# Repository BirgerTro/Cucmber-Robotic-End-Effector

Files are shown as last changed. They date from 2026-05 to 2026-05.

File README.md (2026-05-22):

# Cucmber-Robotic-End-Effector
Proof-of-concept robotic end-effector for autonomous cucumber harvesting in vertical farming. Features soft pneumatic silicone fingers, a rack-and-pinion cutting mechanism, and a rotating roll positioning system. Includes Arduino control code, Python analysis scripts and STEP-files of the relevant designsNTNU Master's thesis, 2026

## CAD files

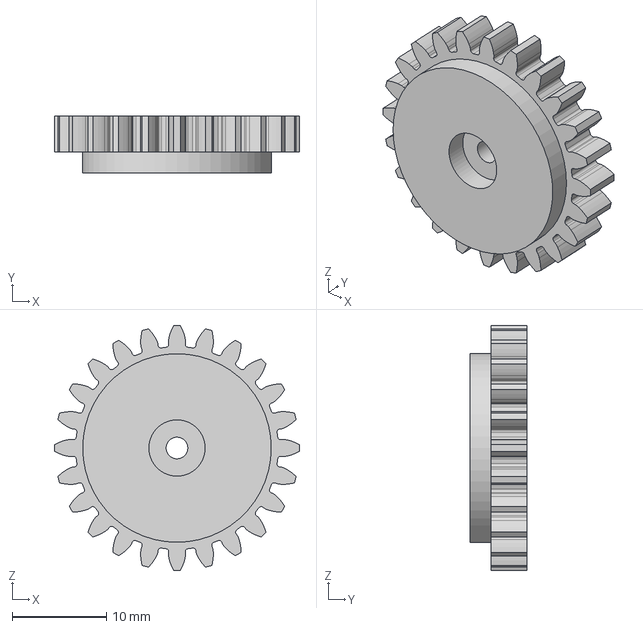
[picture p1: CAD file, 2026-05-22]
STEPfiles/Cutting_system/Knife_spurgear.step
26.0 x 6.01 x 26.0 mm

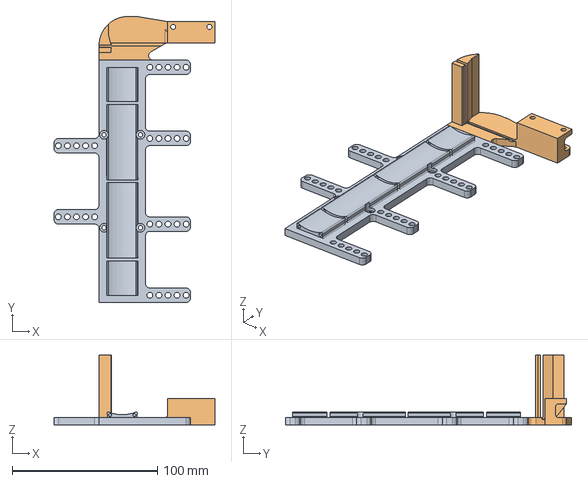
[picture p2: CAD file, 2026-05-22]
STEPfiles/Mechanical_assembly/Palm-with-knife-holder.step
110.9 x 197.0 x 48.0 mm
Mount
Knivoppsettholder

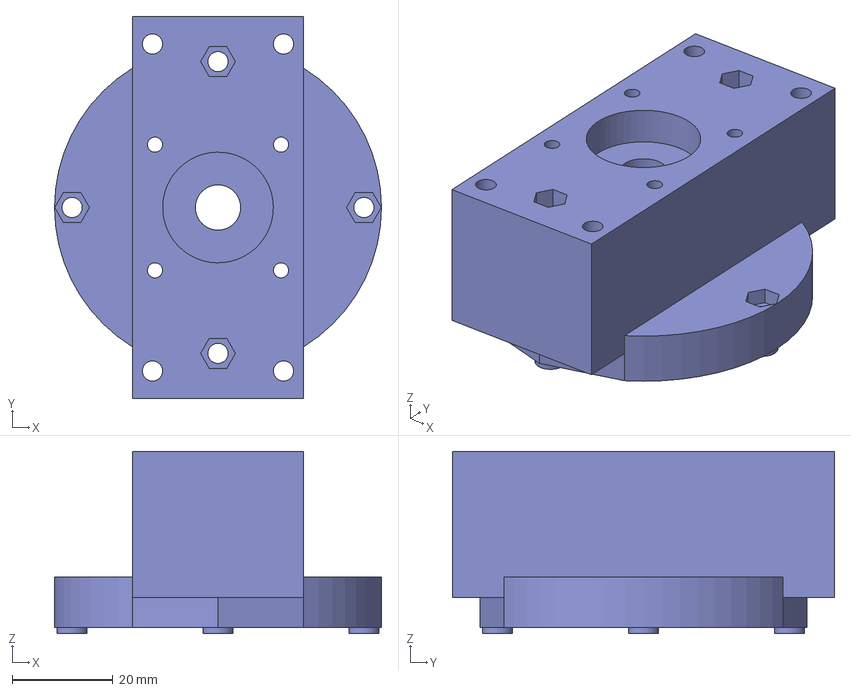
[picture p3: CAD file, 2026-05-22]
STEPfiles/Rotating_system/Wrist-mount.step
65.0 x 76.0 x 36.2 mm

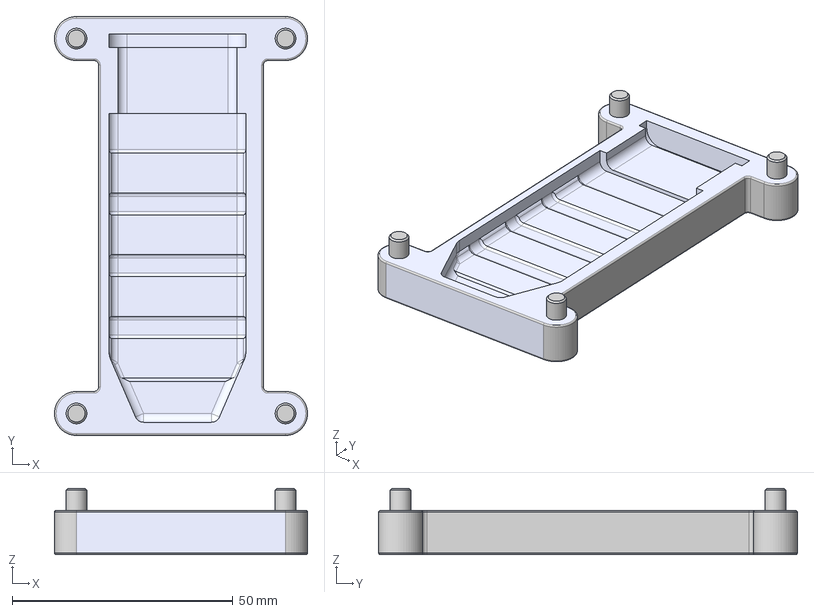
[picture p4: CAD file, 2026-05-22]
STEPfiles/Silicone_fingers/Bottom-mold.step
57.4 x 95.0 x 15.0 mm

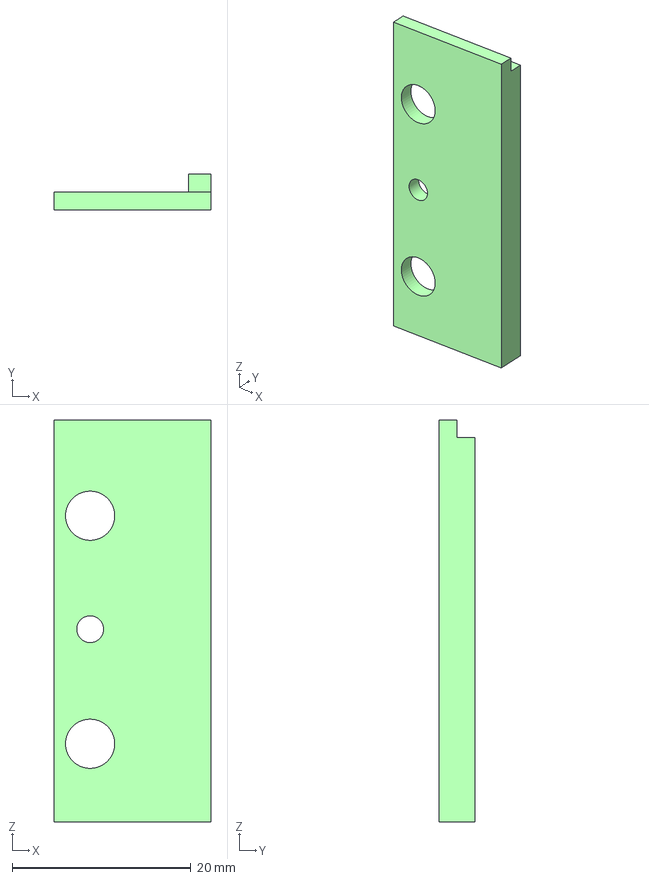
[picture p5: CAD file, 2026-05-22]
STEPfiles/Cutting_system/razorblade-holder.step
17.5 x 4.00 x 45.0 mm

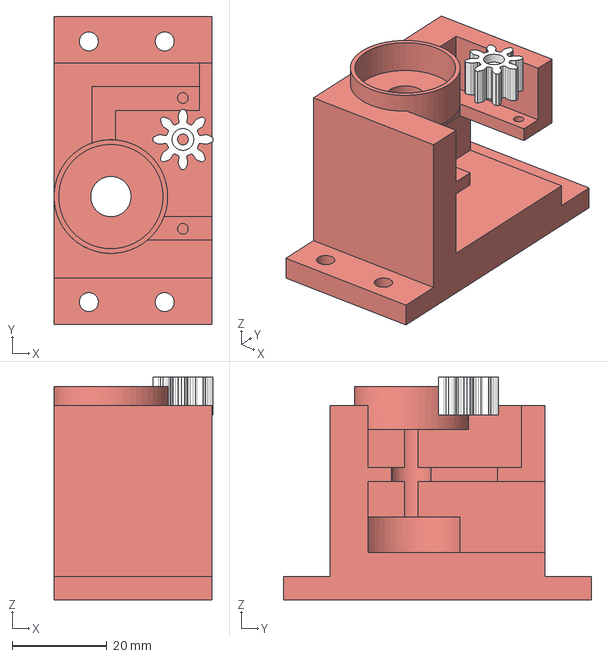
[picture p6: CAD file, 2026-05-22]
STEPfiles/Rotating_system/Wrist_drive-gear.step
33.5 x 65.0 x 47.1 mm

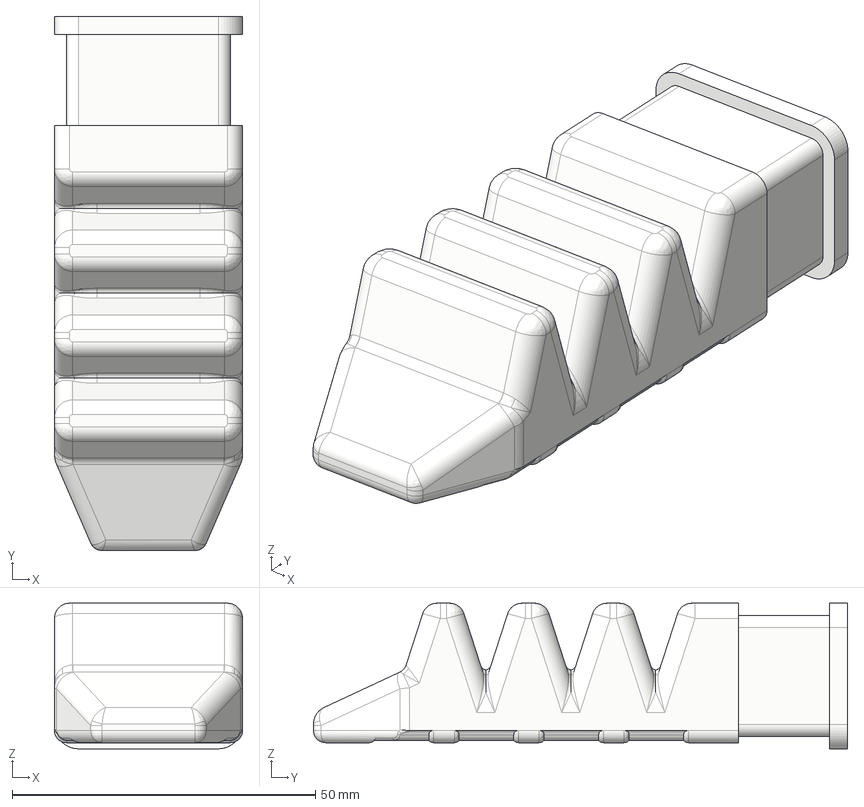
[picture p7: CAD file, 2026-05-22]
STEPfiles/Silicone_fingers/Slicon-finger.step
31.0 x 88.0 x 24.0 mm

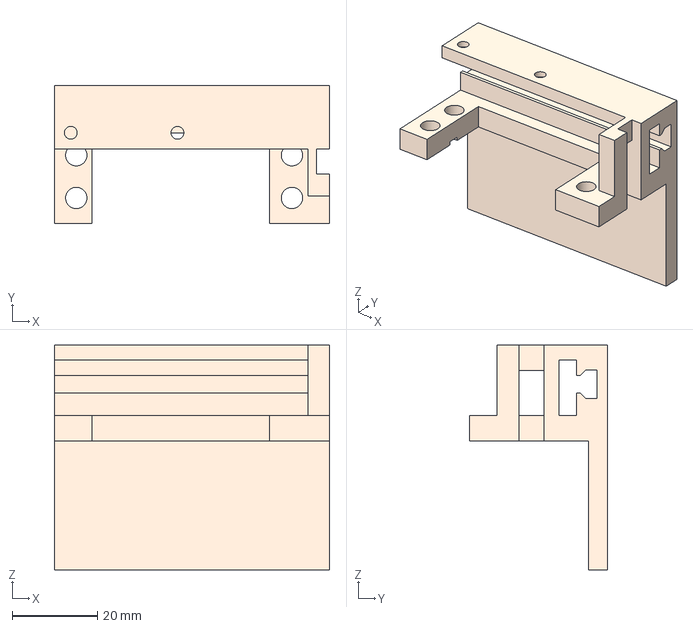
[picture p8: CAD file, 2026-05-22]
STEPfiles/Cutting_system/Motor-Bracket.step
64.4 x 32.4 x 52.7 mm

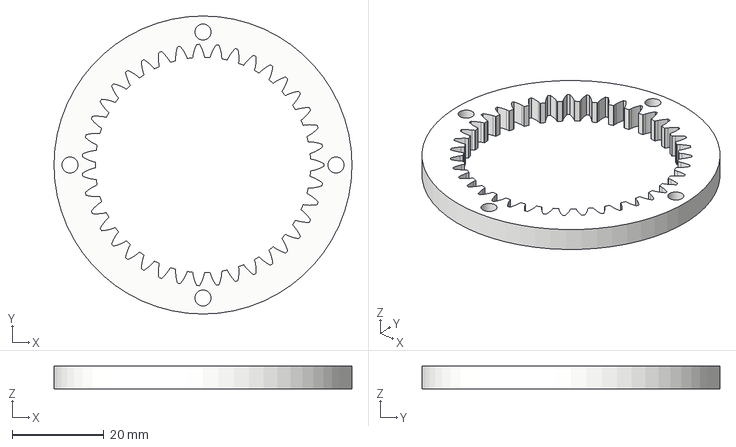
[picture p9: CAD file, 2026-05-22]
STEPfiles/Rotating_system/wrist_outside_gear.step
65.0 x 65.0 x 5.00 mm

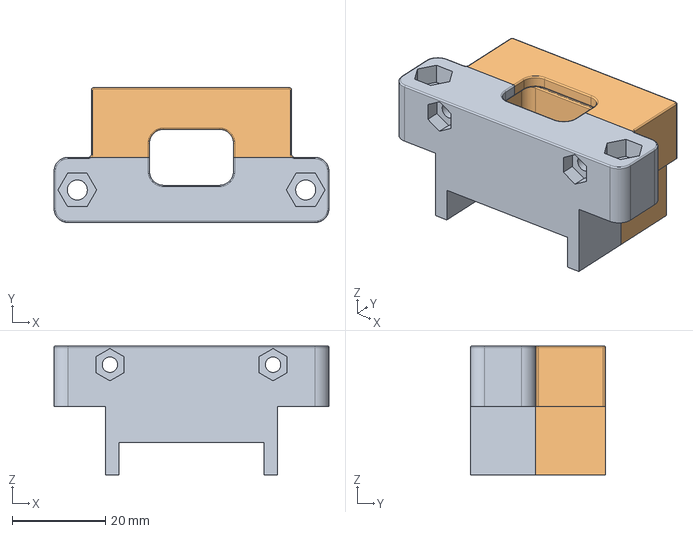
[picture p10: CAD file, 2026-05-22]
STEPfiles/Silicone_fingers/Finger-attachment-to-palm.step
59.0 x 29.0 x 27.6 mm

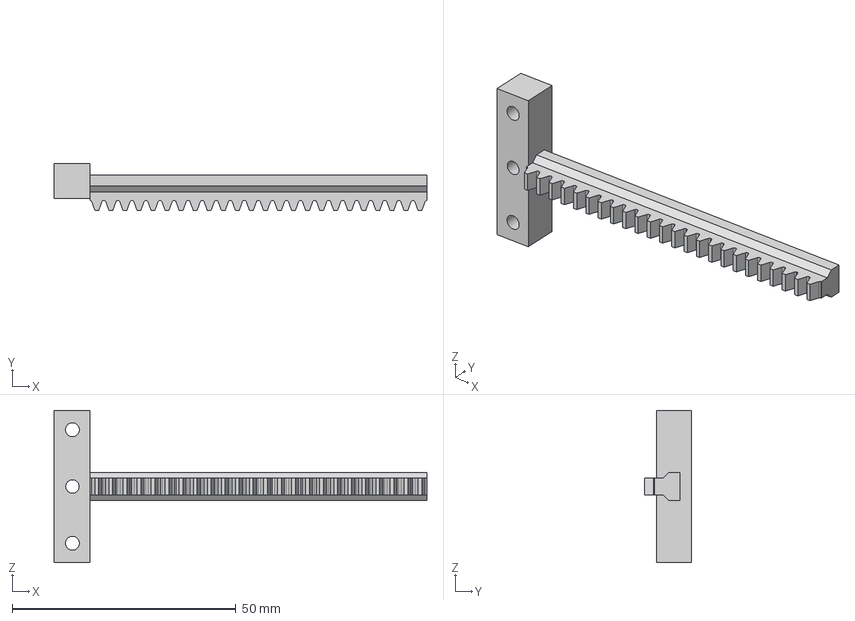
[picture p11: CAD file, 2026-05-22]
STEPfiles/Cutting_system/knife-pusher.step
83.4 x 10.5 x 34.0 mm

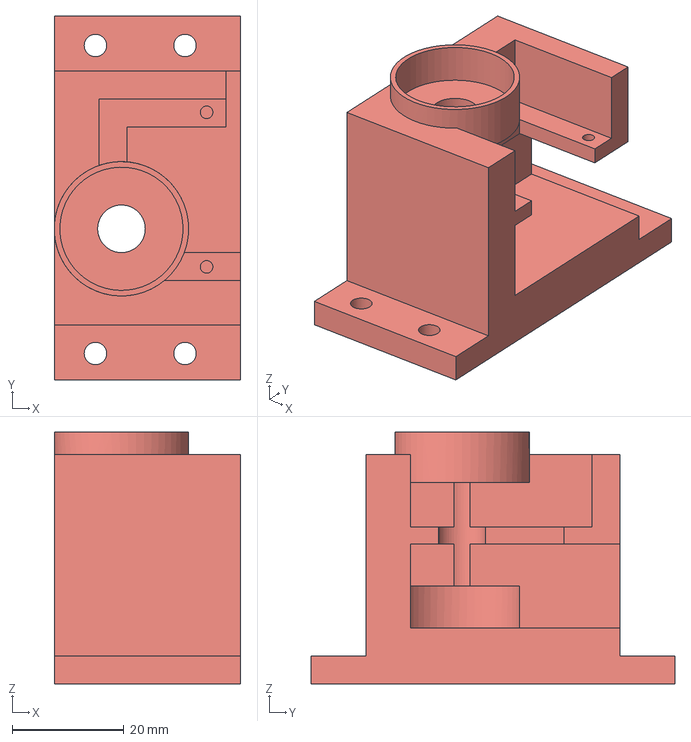
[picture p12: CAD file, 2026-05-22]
STEPfiles/Rotating_system/motor-housing.step
33.3 x 65.0 x 45.0 mm

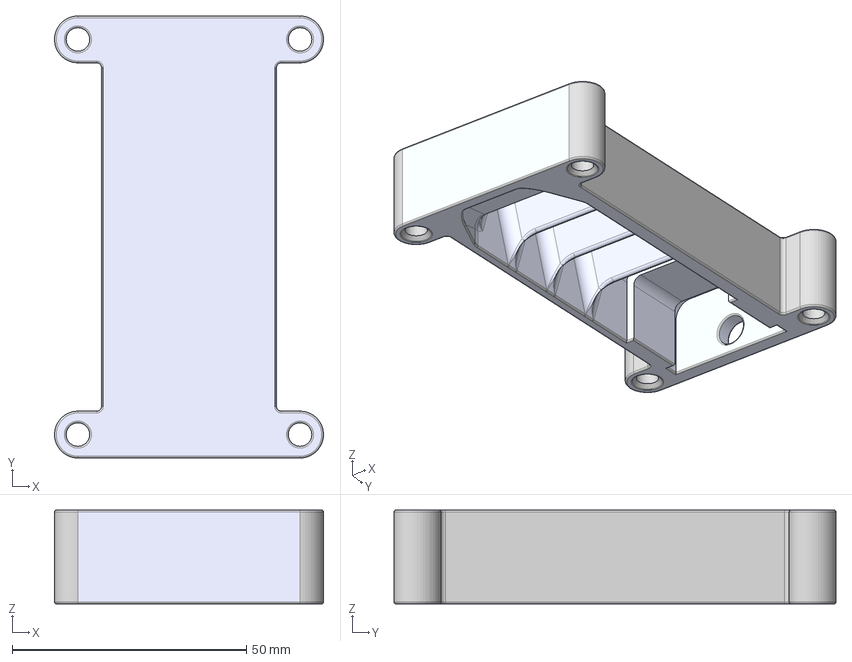
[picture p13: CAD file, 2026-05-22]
STEPfiles/Silicone_fingers/Middle-mold.step
57.4 x 94.3 x 20.0 mm

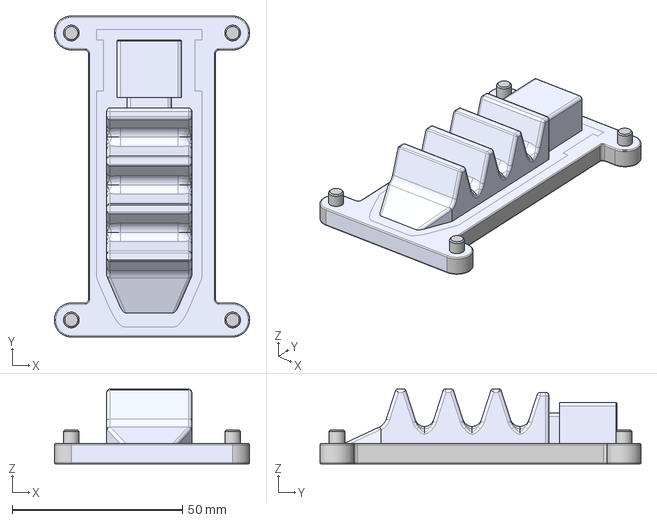
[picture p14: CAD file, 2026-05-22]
STEPfiles/Silicone_fingers/Core-insert.step
57.4 x 94.3 x 22.0 mm

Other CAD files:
STEPfiles/Silicone_fingers/threaded-insert.step

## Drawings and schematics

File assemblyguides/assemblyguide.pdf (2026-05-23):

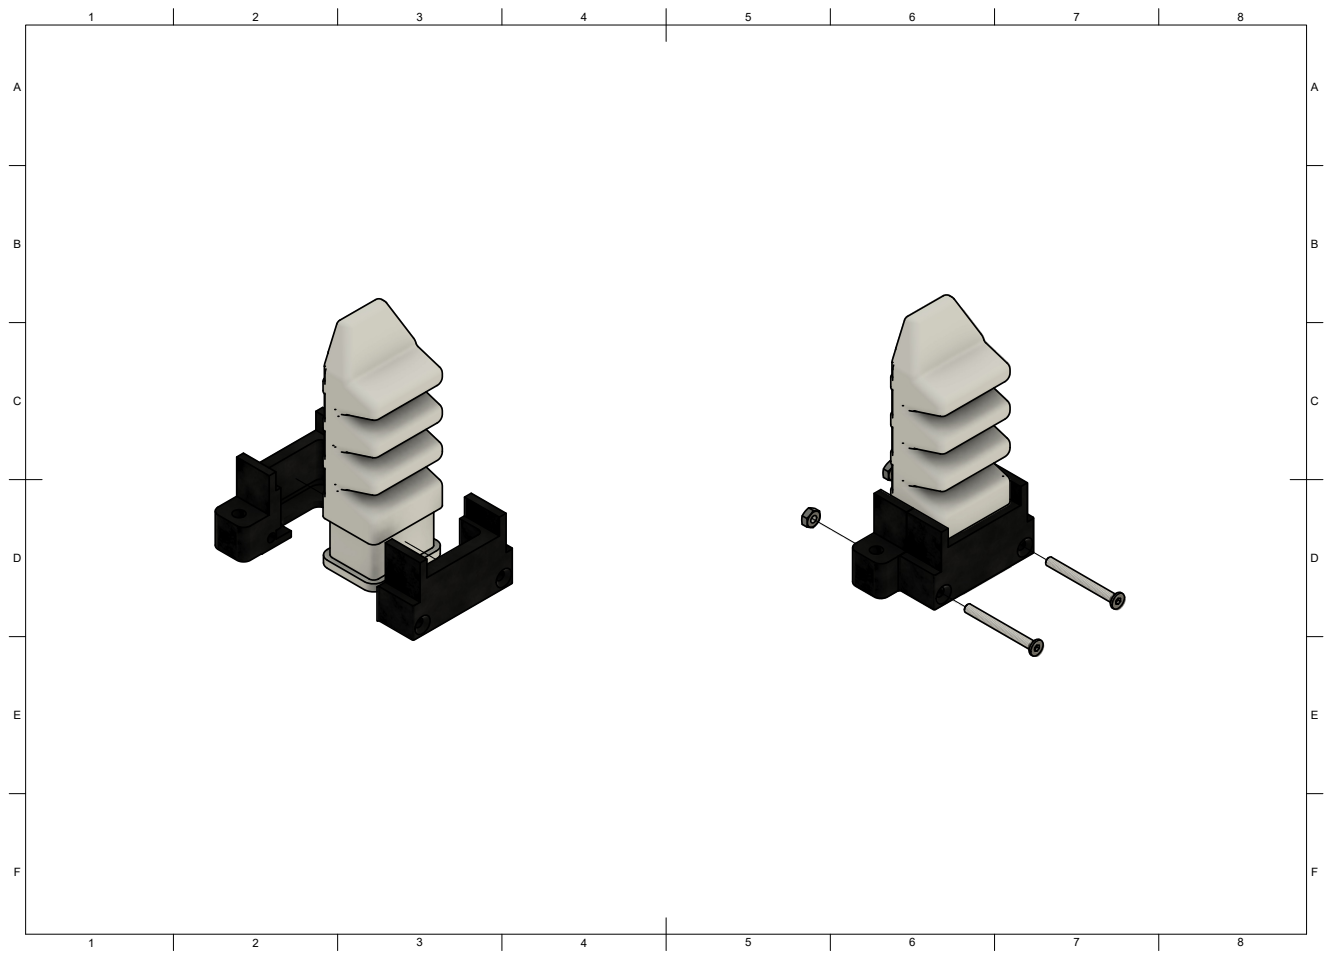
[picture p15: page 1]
8 BCDEF; ABCDEF

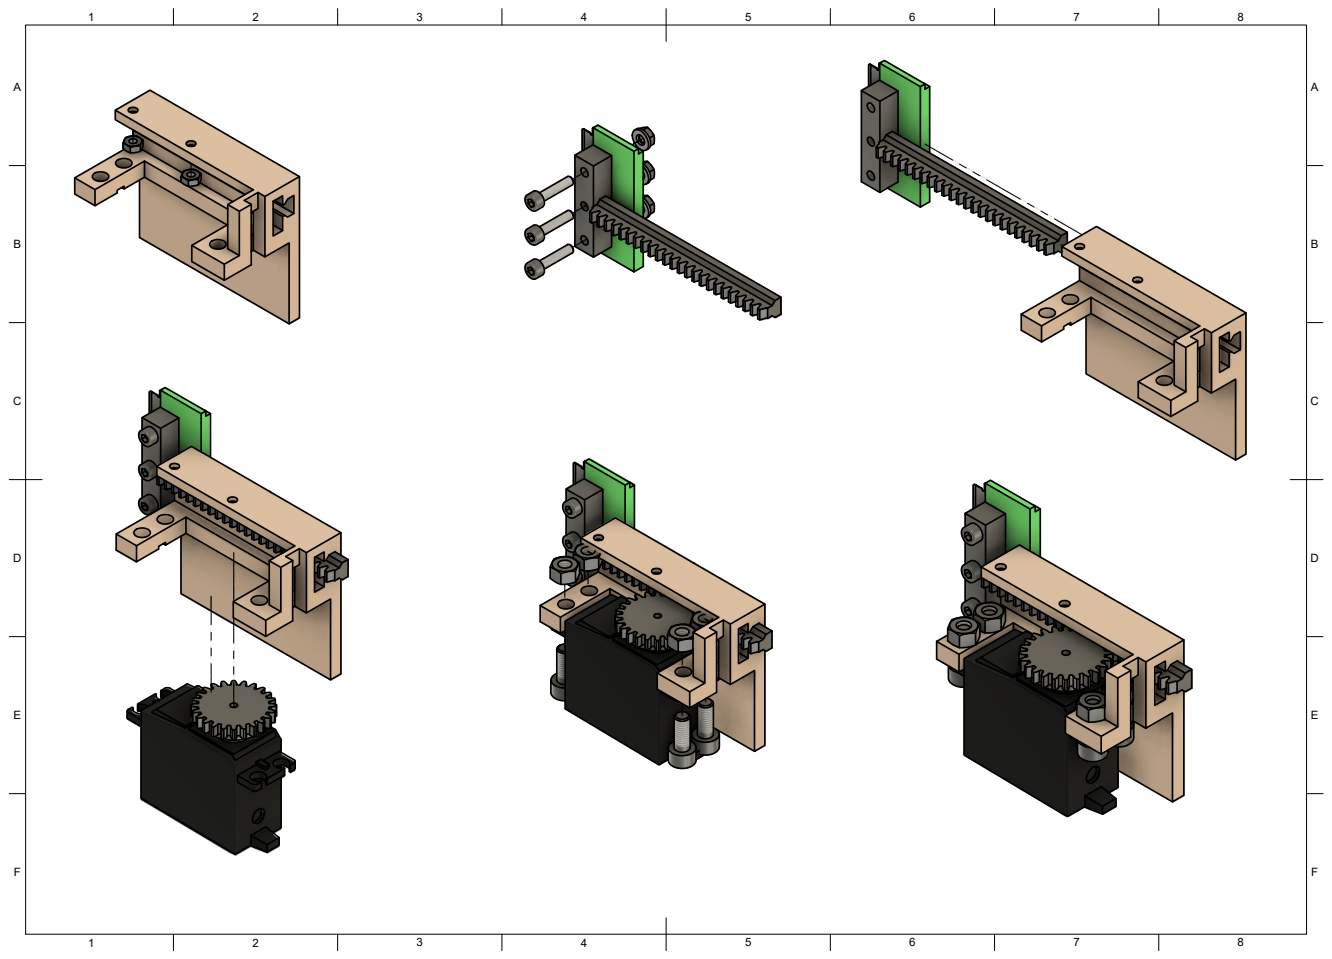
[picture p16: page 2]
8 BCDEF; ABCDEF

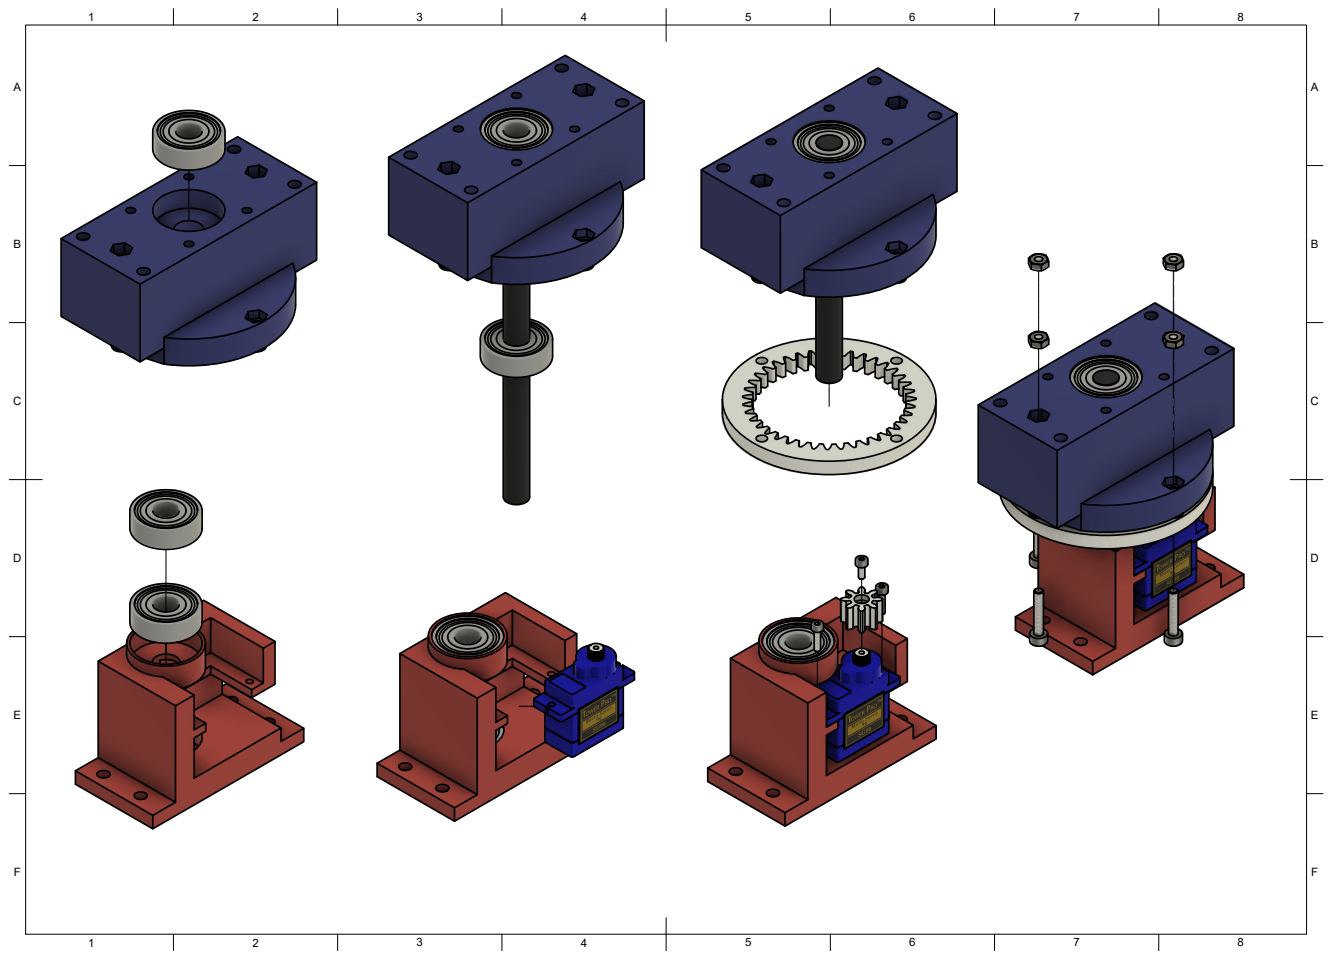
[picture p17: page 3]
8 BCDEF; ABCDEF

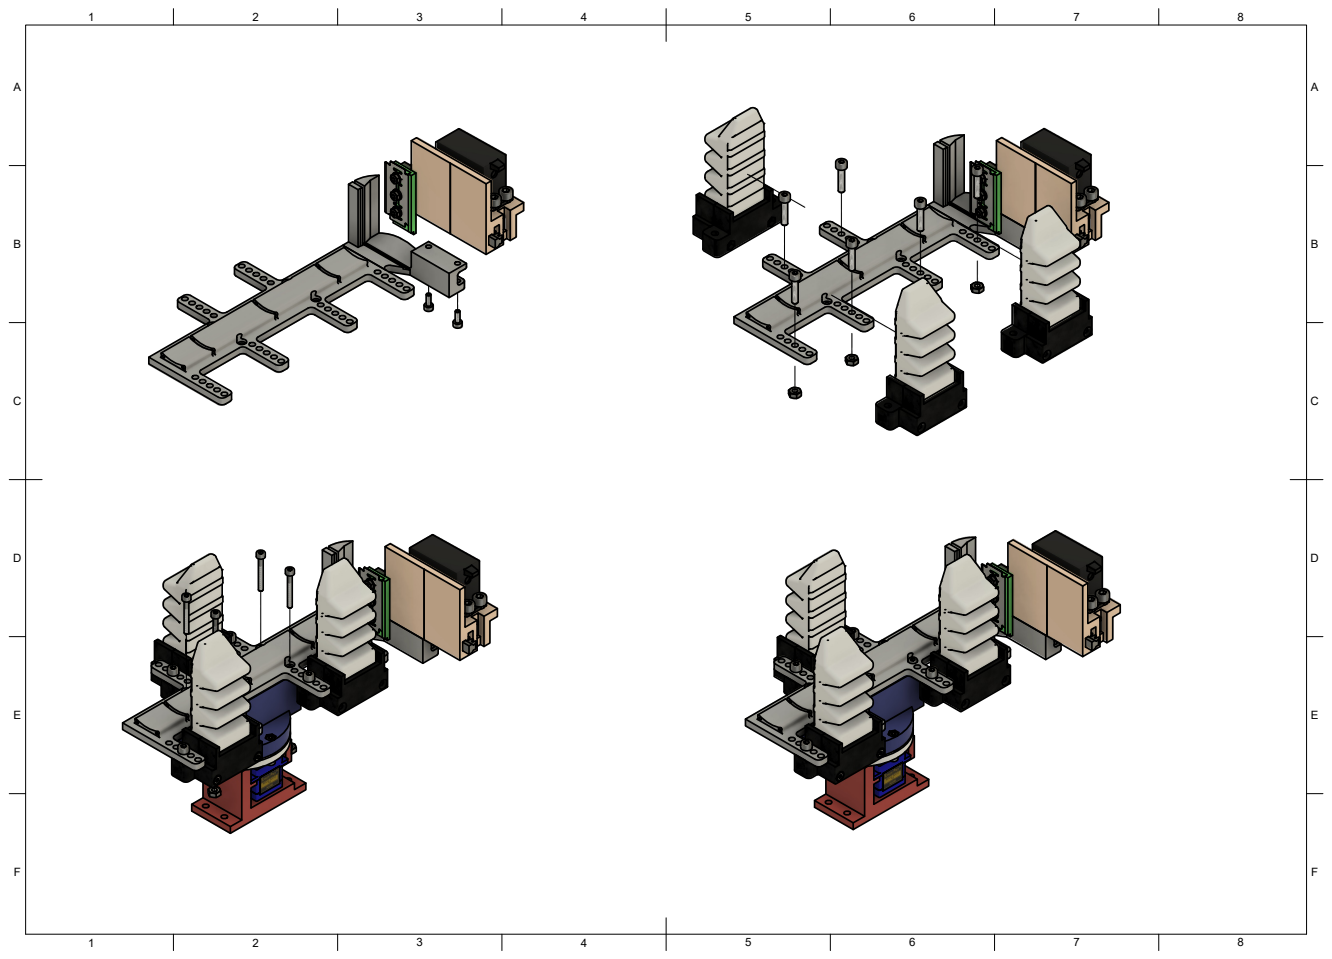
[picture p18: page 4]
8 BCDEF; ABCDEF

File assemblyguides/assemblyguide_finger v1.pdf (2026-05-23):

8 BCDEF; ABCDEF

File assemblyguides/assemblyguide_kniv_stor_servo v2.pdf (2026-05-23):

8 BCDEF; ABCDEF

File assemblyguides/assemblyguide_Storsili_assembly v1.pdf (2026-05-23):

8 BCDEF; ABCDEF

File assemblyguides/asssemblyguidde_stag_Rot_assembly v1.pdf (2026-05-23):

8 BCDEF; ABCDEF

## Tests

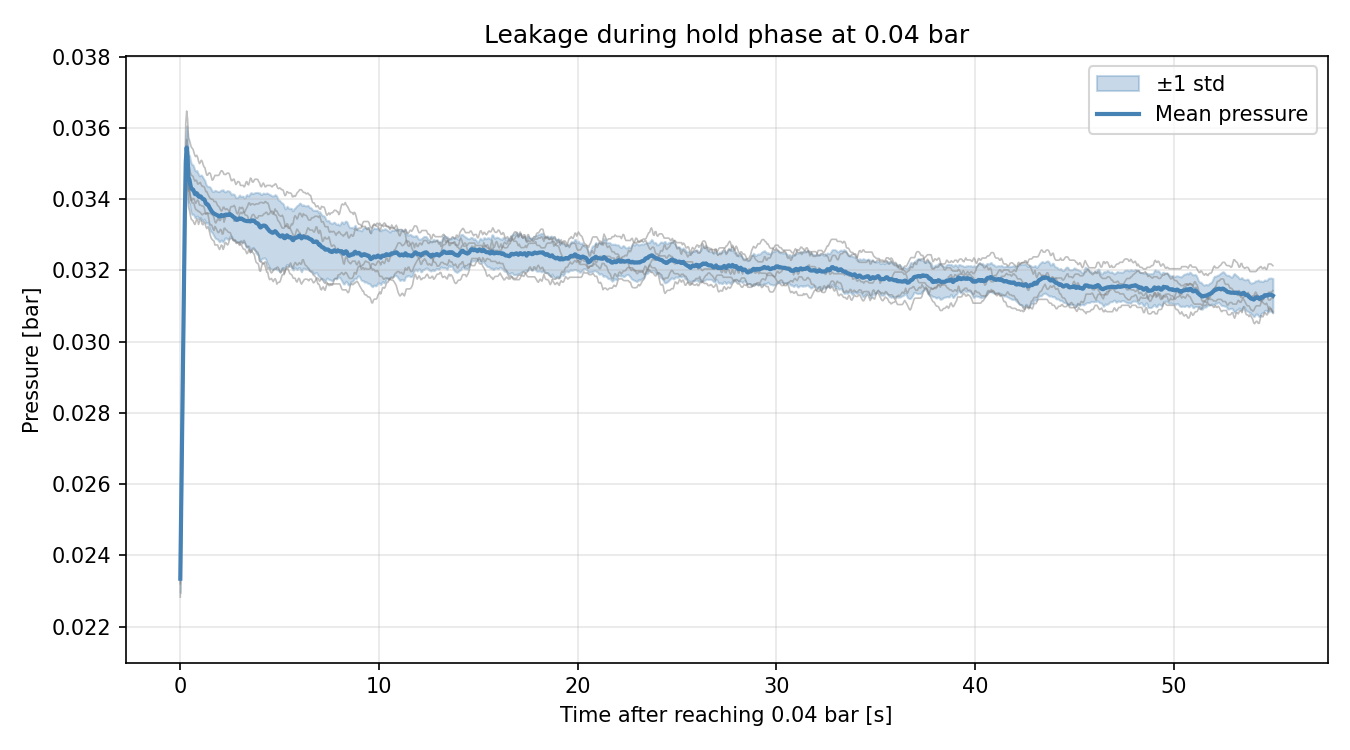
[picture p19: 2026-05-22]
testdata/lekkasjetest_1_finger/0.04bar/lekkasje_0.04bar_1finger.png

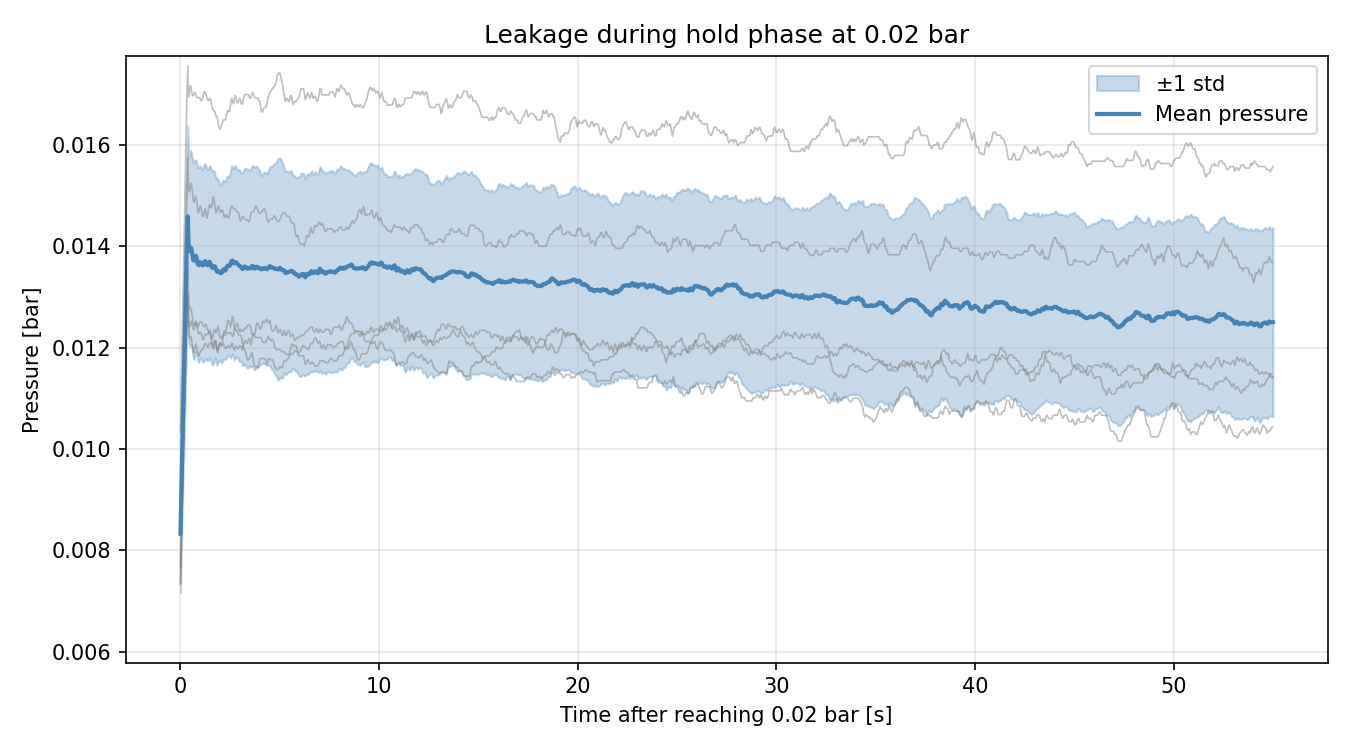
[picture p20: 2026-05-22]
testdata/lekkasjetest_1_finger/0.02bar/lekkasje_0.02bar_1finger.png

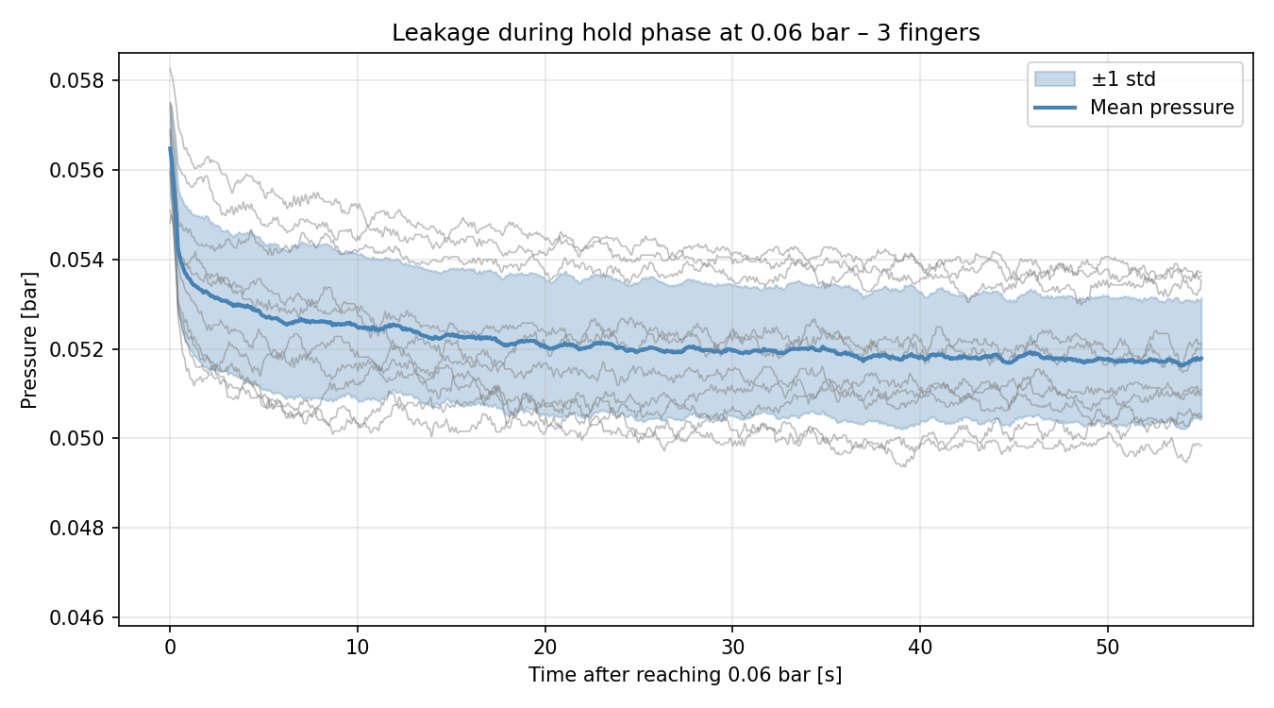
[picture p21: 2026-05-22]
testdata/lekkasjetest_3_fingre/lekkasje_0.06bar_3fingre.png

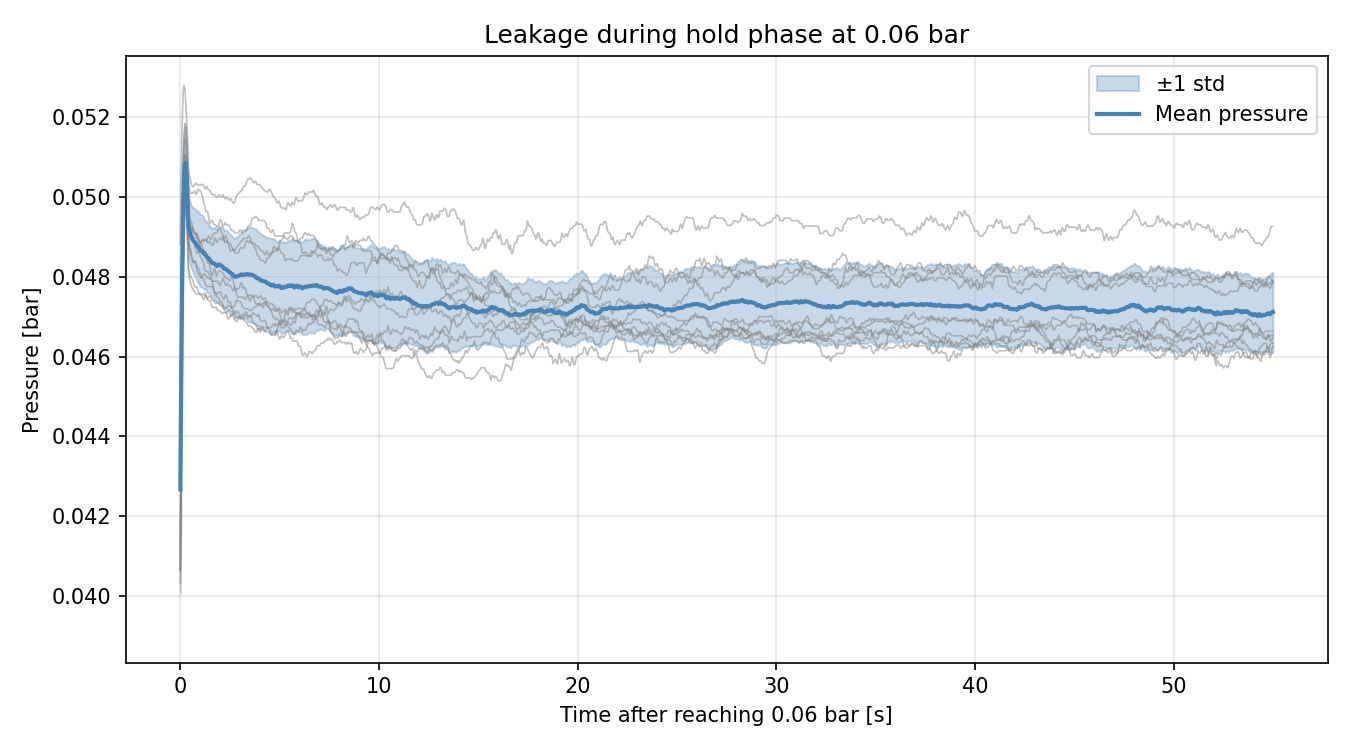
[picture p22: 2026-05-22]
testdata/lekkasjetest_1_finger/0.06bar/lekkasje_0.06bar_1finger.png

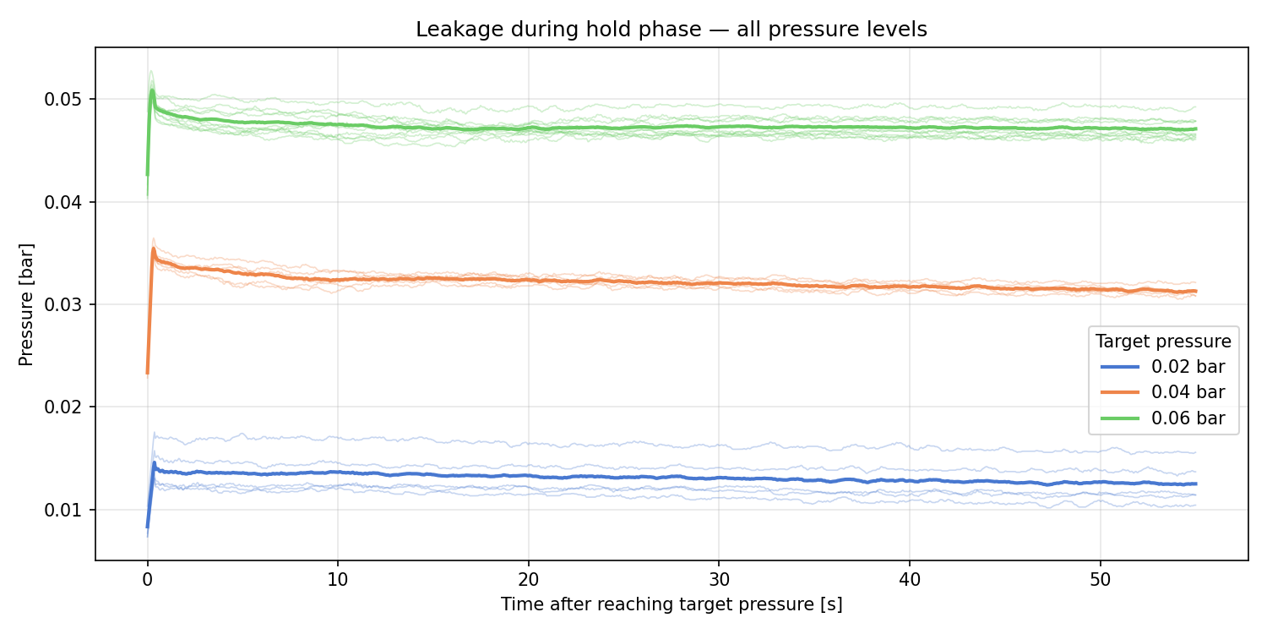
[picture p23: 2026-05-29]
testdata/lekkasjetest_1_finger/lekkasje_all_pressures.png

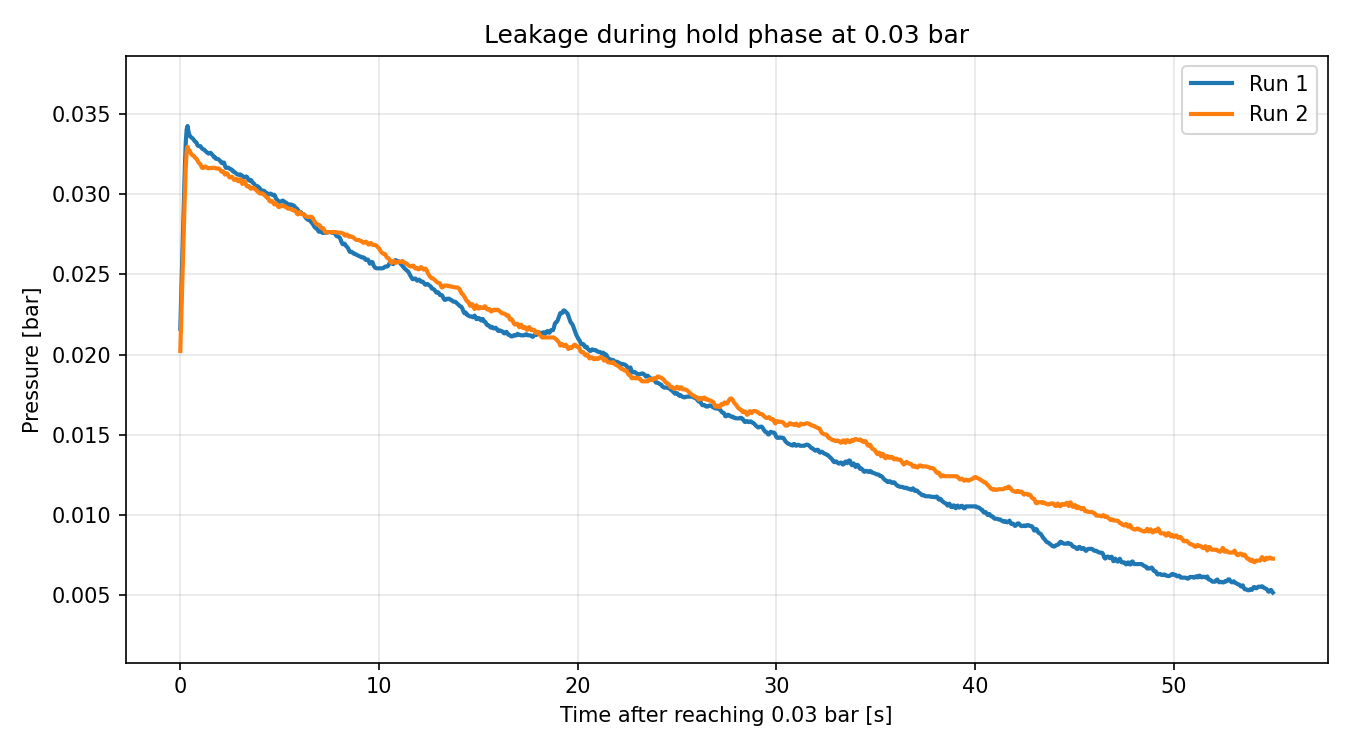
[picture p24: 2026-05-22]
testdata/lekkasjetest_1_liten_finger/litenfinger_smoothedlekkasjetest_1finger_0.03bar60s.png

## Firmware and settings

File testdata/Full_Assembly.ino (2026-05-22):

#include <Wire.h>
#include <Servo.h>

// --------------------------------------------------
// Pin configuration
// --------------------------------------------------
const int valvePin    = 3;    // Pressure valve
const int rotServoPin = 9;    // Rotation servo
const int cutServoPin = 10;   // Cutting servo

// --------------------------------------------------
// Servo objects
// --------------------------------------------------
Servo rotServo;
Servo cutServo;

// --------------------------------------------------
// Servo parameters
// --------------------------------------------------
const int rotStartPos = 90;   // Neutral position
const int cutStartPos = 5;
const int cutAngle    = 140;

// --------------------------------------------------
// Pressure sensor
// --------------------------------------------------
#define SENSOR_ADDR 0x28

const float P_MAX_BAR = 4.137;
const int OUTPUT_MIN = 1638;
const int OUTPUT_MAX = 14745;

// --------------------------------------------------
// System parameters
// --------------------------------------------------
const float targetPressureBar = 0.06;

// --------------------------------------------------
// System states
// --------------------------------------------------
enum State {
  WAIT_ROTATION,
  PRESSURISING,
  WAIT_GRIP_CONFIRM,
  WAIT_CUT_COMMAND,
  WAIT_CUT_CONFIRM,
  WAIT_MANUAL_EXHAUST
};

State currentState = WAIT_ROTATION;

// --------------------------------------------------
// Global variables
// --------------------------------------------------
bool valveClosed = true;
unsigned long lastPrint = 0;
float lastValidPressureBar = 0.0;
int sensorFailCount = 0;

// --------------------------------------------------
// Pressure sensor functions
// --------------------------------------------------
float readPressureBarRaw() {
  Wire.requestFrom(SENSOR_ADDR, 4);

  if (Wire.available() < 4) {
    return -1.0;
  }

  byte b1 = Wire.read();
  byte b2 = Wire.read();

  Wire.read();
  Wire.read();

  byte status = (b1 >> 6) & 0x03;

  if (status != 0) {
    return -1.0;
  }

  int rawPressure = ((b1 & 0x3F) << 8) | b2;

  float pressureBar = ((float)(rawPressure - OUTPUT_MIN) *
                       P_MAX_BAR /
                       (OUTPUT_MAX - OUTPUT_MIN));

  pressureBar = constrain(pressureBar, 0.0, P_MAX_BAR);

  return pressureBar;
}

float readPressureBarStable() {
  for (int i = 0; i < 3; i++) {
    float p = readPressureBarRaw();

    if (p >= 0) {
      lastValidPressureBar = p;
      sensorFailCount = 0;
      return p;
    }

    delay(2);
  }

  sensorFailCount++;
  return lastValidPressureBar;
}

// --------------------------------------------------
// Actuation functions
// --------------------------------------------------
void openValve() {
  digitalWrite(valvePin, HIGH);
}

void closeValve() {
  digitalWrite(valvePin, LOW);
}

void moveRotServoTo(int targetPos) {
  targetPos = constrain(targetPos, 0, 180);
  rotServo.write(targetPos);

  Serial.print("Rotation servo moved to angle: ");
  Serial.println(targetPos);

  delay(2000);
}

void runCutServo() {
  cutServo.write(cutAngle);

  Serial.print("Cutting servo moved to angle: ");
  Serial.println(cutAngle);

  delay(2000);

  cutServo.write(cutStartPos);

  Serial.print("Cutting servo returned to start position: ");
  Serial.println(cutStartPos);
}

// --------------------------------------------------
// User interface functions
// --------------------------------------------------
void printInstructions() {
  Serial.println();
  Serial.println("=== System ready ===");
  Serial.println("Commands:");
  Serial.println("hX   = rotate upwards by X degrees, e.g. h75");
  Serial.println("vX   = rotate downwards by X degrees, e.g. v30");
  Serial.println("g    = confirm rotation angle and start pressurisation");
  Serial.println("f    = confirm that the fingers have gripped");
  Serial.println("k    = activate cutting servo");
  Serial.println("c    = confirm successful cut");
  Serial.println("e    = confirm manual exhaust");
  Serial.println("r    = reset system");
  Serial.println();
}

void resetSystem() {
  closeValve();
  valveClosed = true;

  rotServo.write(rotStartPos);
  cutServo.write(cutStartPos);

  currentState = WAIT_ROTATION;

  Serial.println();
  Serial.println("System reset.");
  Serial.println("Test rotation servo using hX or vX.");
}

void handleRotationCommand(String cmd) {
  if (cmd.startsWith("h")) {
    int value = cmd.substring(1).toInt();
    int target = rotStartPos + value;
    target = constrain(target, 0, 180);

    Serial.print("Testing upward rotation by +");
    Serial.print(value);
    Serial.println(" degrees");

    moveRotServoTo(target);
  }

  else if (cmd.startsWith("v")) {
    int value = cmd.substring(1).toInt();
    int target = rotStartPos - value;
    target = constrain(target, 0, 180);

    Serial.print("Testing downward rotation by -");
    Serial.print(value);
    Serial.println(" degrees");

    moveRotServoTo(target);
  }
}

// --------------------------------------------------
// Setup
// --------------------------------------------------
void setup() {
  Wire.begin();
  Serial.begin(115200);

  pinMode(valvePin, OUTPUT);
  closeValve();

  rotServo.attach(rotServoPin);
  cutServo.attach(cutServoPin);

  rotServo.write(rotStartPos);
  cutServo.write(cutStartPos);

  delay(500);

  printInstructions();
  resetSystem();
}

// --------------------------------------------------
// Main loop
// --------------------------------------------------
void loop() {
  float pressureBar = readPressureBarStable();

  // Periodic state and pressure output
  if (millis() - lastPrint > 300) {
    lastPrint = millis();

    Serial.print("State: ");

    switch (currentState) {
      case WAIT_ROTATION:       Serial.print("WAIT_ROTATION"); break;
      case PRESSURISING:        Serial.print("PRESSURISING"); break;
      case WAIT_GRIP_CONFIRM:   Serial.print("WAIT_GRIP_CONFIRM"); break;
      case WAIT_CUT_COMMAND:    Serial.print("WAIT_CUT_COMMAND"); break;
      case WAIT_CUT_CONFIRM:    Serial.print("WAIT_CUT_CONFIRM"); break;
      case WAIT_MANUAL_EXHAUST: Serial.print("WAIT_MANUAL_EXHAUST"); break;
    }

    Serial.print(" | Pressure: ");
    Serial.print(pressureBar, 4);
    Serial.print(" bar");

    if (sensorFailCount > 0) {
      Serial.print(" | Sensor fail count: ");
      Serial.print(sensorFailCount);
    }

    Serial.println();
  }

  // Automatic valve closing when target pressure is reached
  if (currentState == PRESSURISING &&
      !valveClosed &&
      pressureBar >= targetPressureBar) {

    closeValve();
    valveClosed = true;
    currentState = WAIT_GRIP_CONFIRM;

    Serial.println();
    Serial.print("Target pressure reached: ");
    Serial.print(pressureBar, 4);
    Serial.println(" bar");
    Serial.println("Confirm grip using 'f'");
  }

  // Read serial command
  if (Serial.available() > 0) {
    String cmd = Serial.readStringUntil('\n');
    cmd.trim();

    if (cmd.length() == 0) {
      return;
    }

    // Reset is always available
    if (cmd == "r") {
      resetSystem();
      return;
    }

    switch (currentState) {
      case WAIT_ROTATION:
        if (cmd.startsWith("h") || cmd.startsWith("v")) {
          handleRotationCommand(cmd);
        }
        else if (cmd == "g") {
          currentState = PRESSURISING;
          openValve();
          valveClosed = false;

          Serial.println("Rotation confirmed.");
          Serial.println("Pressurising fingers to 0.0525 bar...");
        }
        else {
          Serial.println("Invalid command. Use hX, vX, or g.");
        }
        break;

      case PRESSURISING:
        Serial.println("Automatic pressurisation in progress...");
        break;

      case WAIT_GRIP_CONFIRM:
        if (cmd == "f") {
          currentState = WAIT_CUT_COMMAND;
          Serial.println("Grip confirmed.");
          Serial.println("Send 'k' to activate the cutting servo.");
        }
        else {
          Serial.println("Invalid command. Use 'f' when grip is confirmed.");
        }
        break;

      case WAIT_CUT_COMMAND:
        if (cmd == "k") {
          Serial.println("Activating cutting servo...");
          runCutServo();

          currentState = WAIT_CUT_CONFIRM;
          Serial.println("Confirm cut using 'c'");
        }
        else {
          Serial.println("Invalid command. Use 'k' to cut.");
        }
        break;

      case WAIT_CUT_CONFIRM:
        if (cmd == "c") {
          currentState = WAIT_MANUAL_EXHAUST;
          Serial.println("Cut confirmed.");
          Serial.println("Manually release air through exhaust and confirm using 'e'.");
        }
        else {
          Serial.println("Invalid command. Use 'c' when cut is confirmed.");
        }
        break;

      case WAIT_MANUAL_EXHAUST:
        if (cmd == "e") {
          Serial.println("Exhaust confirmed.");
          Serial.println("Cycle complete.");
          resetSystem();
        }
        else {
          Serial.println("Invalid command. Use 'e' when air has been released.");
        }
        break;
    }
  }
}
